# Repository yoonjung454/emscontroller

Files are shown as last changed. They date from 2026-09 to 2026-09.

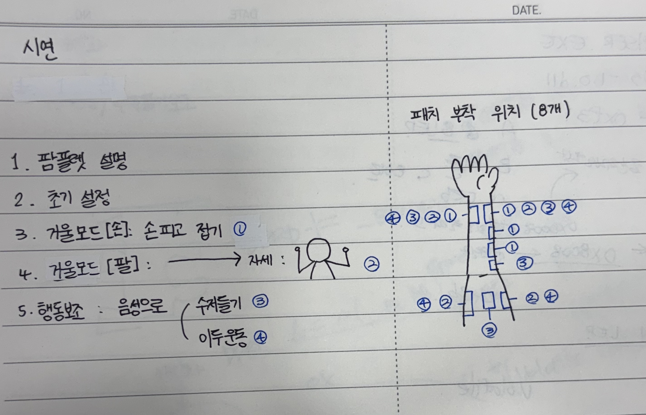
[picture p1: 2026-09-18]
docs/시연순서_패치위치선정.jpg

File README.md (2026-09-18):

# EMS Controller

EMS(전기근육자극) 기반 뇌졸중·마비 환자 재활 보조 시스템 — 한성공학경진대회 16번 팀.

카메라(MediaPipe)로 손/팔의 움직임을 실시간으로 인식해 목표 동작으로 삼고, 그 목표에
가까워지도록 EMS 자극 세기를 자동으로 조절하는 폐루프 제어 시스템입니다.

```
[카메라] --MediaPipe 인식--> [PC: 웹앱]
                                  |  목표 vs 실제 오차 계산 → 폐루프 제어값(0~100) 산출
                                  v
                       [Web Serial, 19200bps]
                                  v
                 [Arduino Nano + openEMSstim 펌웨어]
                                  v
                     [TENS 7000 저주파 자극기] → 전극 패드 → 손/팔 근육
```

## 폴더 구조

| 경로 | 내용 |
|---|---|
| `app.js`, `index.html`, `hand_camera.py`, `*.task`, `run_server.bat` | **웹앱** (실제 시연에 쓰는 최종 버전). `run_server.bat` 실행 후 Chrome/Edge로 `http://localhost:8000` 접속. 거울/팔 인식/행동 보조/테스트 4가지 모드 지원 (행동 보조 모드 안에 이두운동·수저 들기 보조와 "탱글이" 음성 비서가 포함됨). |
| `docs/` | 대회 제출용 보고서·전시 판넬·설계 정리 문서·시연 대본과 Q&A·시연 시 패치 위치 사진·개발 커밋 히스토리 원문·팀 대화 기반 프로젝트 진행 타임라인. |
| `hardware/case/` | 보드 케이스 3D 프린팅 설계(STL)와 조립 영상. |
| `python-ems_closed_loop/` | 웹앱 이전에 먼저 만들어진 **파이썬(Tkinter) 프로토타입**. 같은 폐루프 제어 로직을 파이썬으로 구현한 버전 (참고/백업용, 시연에는 웹앱을 사용). |
| `firmware/openemsstim_serial_controller/` | **현재 실제 보드에 올라가 있는 최신 Arduino 펌웨어** (openEMSstim 기반, PING/ARM/SET/STOP 시리얼 프로토콜). |
| `firmware/channel_alternate_test/` | 채널1/채널2가 실제로 어느 핀에서 나오는지 확인할 때 쓴 진단용 스케치. |
| `archive/early_prototypes/` | 현재 구조로 정착하기 전, 초기에 시도했던 별도의 하드웨어 프로토타입(피드백 장갑, 주먹 인식 버튼 테스트) 스케치 — 개발 히스토리 보존용, 실제 시연과는 무관. |

> 예전에는 2026-08-23 시점 구버전 스냅샷(`mediapipehand/` 폴더)과 그걸 파일
> 하나로 번들링한 `ems_demo_standalone.html`도 참고용으로 같이 두었으나,
> 이 저장소의 목적이 "최종 기록/포트폴리오"로 정리되면서 혼동을 줄이기 위해
> 삭제했습니다. 필요하면 git 히스토리에서 언제든 복원할 수 있습니다.

이 저장소에는 없지만 함께 촬영해둔 시연/조립 영상(수백 MB~1GB대 mp4)은 GitHub
용량 제한(파일당 100MB) 때문에 git에는 올리지 않았습니다 — 원본은 팀 공유
드라이브에 그대로 보관되어 있으니, 포트폴리오에 영상이 필요하면 YouTube나
Drive 링크로 별도 공유하세요.

## 안전 관련 필수 사항

- `app.js`의 `config.safety.maxIntensity`(안전 최대 제어값)는 기본값 0으로, 사람이 화면에서
  직접 값을 입력하기 전까지 실제 EMS 출력이 나가지 않습니다.
- 연속 자극 시간 제한(기본 60초)과 비상정지(스페이스바/ESC/화면 버튼)가 구현되어
  있습니다. (전체 실험 제한시간은 실사용 편의를 위해 제거했고, 경과 시간은 화면에
  참고용으로만 표시됩니다.)
- 실제 사람 몸에 전기자극을 가하는 시스템이므로, 안전 상한값은 반드시 전문가 감독 하에
  결정해야 합니다.

## 실행 방법

1. `run_server.bat` 더블클릭 (Python 필요)
2. Chrome 또는 Edge로 `http://localhost:8000` 접속
3. 모드 선택 → 카메라 실행 → 초기값(캘리브레이션) 측정 → Arduino 연결 → 안전값 설정 → 제어 시작

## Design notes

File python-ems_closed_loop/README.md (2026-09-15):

# AI 비전 피드백 기반 폐루프 EMS 손동작 제어 시스템

카메라(MediaPipe)로 손가락 굽힘 정도를 실시간으로 측정하고, 자연어 명령에서 뽑아낸 목표
굽힘값과 비교해 OpenEMSstim(Arduino Nano)에 보내는 EMS 제어값(0~100, **mA 아님**)을
자동으로 올리고 내리는 폐루프 제어 프로토타입입니다.

> ⚠️ **먼저 읽어주세요**: 이 프로그램은 사람 몸에 전기 자극을 가하는 하드웨어를 다룹니다.
> 기본 실행 모드는 항상 **시뮬레이션**이고, 실제 EMS 출력은 `--live-serial`(또는 `--live`)
> 플래그 + `config.json`의 `safety.safety_max_intensity`를 담당자가 직접 0보다 크게 설정해야만
> 나갑니다. 이 값을 임의로 정해주지 않습니다 — 아래 "안전 경고" 섹션을 반드시 읽으세요.

---

## 1. 전체 시스템 구조 요약

```
[노트북]
  자연어 명령 입력 (GUI)
        │
        ▼
  command_interpreter.py  ── 규칙 기반으로 "목표 굽힘 %" 추출 (LLM 없이 동작, 나중에 교체 가능)
        │
        ▼
  adaptive_model.py       ── 과거 세션 데이터로 "이 사람은 이 정도 자극값이면 대략 이만큼 구부러짐"을 추정
        │ (초기 자극값 제안, 항상 safety로 재검증됨)
        ▼
  controller.py            ── target% vs current% 오차 기반 폐루프 제어 (P 또는 PID, 단계 제한)
        │                          ▲
        │ EMS 제어값(0~100)         │ current% (필터링된 굽힘값)
        ▼                          │
  safety_manager.py  ◄─────────────┤   (모든 실제 출력은 여기를 반드시 통과)
        │                          │
        ▼                          │
  serial_link.py  ──USB(19200bps)──▶  Arduino Nano (openemsstim_serial_controller.ino)
        │                                   │
        │                                   ▼
        │                          EMSChannel.setIntensity() → AD5252 디지털 가변저항
        │                                   │
        │                                   ▼
        │                     외부 EMS 기기 → 패드 → 손가락 굽힘근 자극
        │
        ▼
  vision_tracker.py  ◄── OpenCV 카메라 + MediaPipe Hand Landmarker (21개 랜드마크)
        │  (검지/중지/약지/새끼 4개 손가락의 MCP/PIP/DIP 각도 → 0~100% 굽힘값)
        ▼
  data_logger.py  ── 매 tick을 CSV로 기록 (adaptive_model 학습 데이터 겸 실험 로그)
        │
        ▼
  gui.py  ── 카메라 영상, 관절, 명령창, 그래프, 비상정지 버튼 등 표시 (Tkinter)
```

시뮬레이션 모드(`simulator.py`)는 위 그림에서 `vision_tracker.py`와 `serial_link.py`를 각각
`HandDynamicsSimulator`, `SimulatedArduino`로 바꿔 끼우는 것뿐입니다. `controller.py`,
`command_interpreter.py`, `safety_manager.py`, `data_logger.py`, `gui.py`는 실제/시뮬레이션
어느 쪽이든 완전히 동일한 코드로 동작합니다.

---

## 2. 핵심 가정과 실제 장치에서 확인해야 하는 항목

이 코드는 아래 항목을 **실제로 확인**했거나, 확인이 필요하다고 명시합니다 (임의로 지어낸
핀 번호/클래스는 없습니다):

| 항목 | 상태 | 확인한 방법 / 확인해야 할 것 |
|---|---|---|
| `EMSChannel::setIntensity(int)`가 0~100을 받는다 | ✅ 확인함 | 공식 `EMSChannel.cpp` 원문 확인 (`arduino-openEMSstim.ino`도 동일) |
| 채널1 핀 = `(5, 4, A2, wiperIndex=1)`, 채널2 핀 = `(6, 7, A3, wiperIndex=3)` | ✅ 공식 예제 값 확인함 | **하지만 팀 보드가 이 배선과 같은지는 당신이 직접 확인해야 합니다** — 아래 참고 |
| `AD5252 digitalPot(0)` (I2C 주소 오프셋 0) | ✅ 공식 예제 값 확인함 | 팀 보드의 실제 I2C 주소가 다르면 `openemsstim_serial_controller.ino`의 이 줄을 수정 |
| `Serial.begin(19200)` (USB 통신 속도) | ✅ 공식 펌웨어 기본값 확인함 | `config.json`의 `serial.baud_rate`와 반드시 일치시킬 것 |
| `applySignal()`/`check()`가 millis() 기반으로 자동 정지한다 | ✅ 확인함 | 그대로 재사용 (우리가 새로 만들지 않음) |
| CH340 드라이버로 Arduino Nano 호환보드가 보인다 | ⚠️ 확인 필요 | 처음 연결 시 Windows 장치 관리자에서 "USB-SERIAL CH340" 포트가 보이는지 확인 |
| 채널 1만 정상 작동, 채널 2는 하드웨어 고장 | ✅ 팀이 알려준 정보를 그대로 반영 | `arduino/hardware_config.h`의 `CHANNEL_2_ENABLED false` |
| 사람마다 안전한 최대 자극 세기 | ❌ **이 코드는 정하지 않음** | 전문가 감독 하에 직접 결정 후 `config.json`에 입력 |
| 웹캠이 약 30~45도 방향(손등+손가락 관절이 보이는 각도)에서 촬영된다 | 권장 사항 | 카메라를 손 위쪽 대각선에서 손등을 향하도록 배치 |

**핀 배선 재확인 방법**: `arduino/openemsstim_serial_controller.ino`를 열어
`EMSChannel emsChannel1(...)`, `EMSChannel emsChannel2(...)` 두 줄을 찾으세요. 괄호 안 숫자가
팀이 실제로 납땜/배선한 핀 번호와 일치하는지 멀티미터나 회로도로 확인한 다음 진행하세요.
다르면 숫자만 실제 배선에 맞게 고치면 됩니다 (클래스 구조는 그대로 사용).

---

## 3. 프로젝트 폴더 구조

```
ems_closed_loop/
├── main.py                                  # 진입점 (CLI 인자 처리, 전체 조립, 워커 스레드 시작)
├── gui.py                                    # Tkinter GUI
├── vision_tracker.py                         # 카메라 + MediaPipe Hand Landmarker
├── command_interpreter.py                    # 자연어 → 목표 굽힘 % (규칙 기반, LLM 교체 가능 구조)
├── controller.py                             # 폐루프 제어 (P / PID)
├── adaptive_model.py                         # 개인화 모델 (선형/2차 회귀로 초기 자극값 추정)
├── serial_link.py                            # PC ↔ Arduino 시리얼 통신
├── safety_manager.py                         # 모든 안전 규칙의 단일 창구
├── simulator.py                              # 카메라/Arduino 없이 테스트하는 시뮬레이션
├── data_logger.py                            # CSV 로깅 + 과거 세션 불러오기
├── config.py                                 # 설정 데이터클래스 + config.json 로드/저장
├── config.json                               # (최초 실행 시 자동 생성됨. 안전 상한값은 0으로 시작)
├── requirements.txt
├── README.md                                 # 이 파일
├── hand_landmarker.task                      # MediaPipe 모델 파일
├── arduino/
│   ├── openemsstim_serial_controller.ino     # 공식 펌웨어 + 시리얼 명령 패치
│   └── hardware_config.h                     # 채널 활성화/BLE/타임아웃 등 우리 쪽 설정
├── tests/
│   ├── test_command_interpreter.py
│   ├── test_controller.py
│   ├── test_safety_manager.py
│   ├── test_adaptive_model.py
│   └── test_config.py
├── logs/                                      # 세션별 CSV (실행 시 자동 생성)
└── models/
    └── adaptive_model.json                    # 학습된 개인화 모델 (있으면 자동 로드)
```

각 파일은 이미 이 폴더에 전체 코드로 작성되어 있고, `python -m unittest discover -s tests`로
38개 단위 테스트가 모두 통과하는 상태입니다. (아래 "9. 시뮬레이션 실행 방법"에서 직접 확인할 수
있습니다.) 이 문서에서는 코드를 다시 옮겨 적지 않고, 무엇이 어디 있는지와 어떻게 실행하는지에
집중합니다.

---

## 4. 각 파일의 역할 (요약)

- **main.py** — CLI 플래그(`--live`, `--live-camera`, `--live-serial`)를 해석해 실제/시뮬레이션
  구성요소를 선택하고, `ControlLoopWorker`를 백그라운드 스레드로 돌리며 GUI를 메인 스레드에서 띄웁니다.
- **gui.py** — 카메라 영상, 관절, 명령 입력창, 30/60/90% 버튼, 캘리브레이션 버튼, 포트 선택,
  실시간 수치, 그래프, CSV 상태, 큰 빨간 비상정지 버튼을 그립니다. 워커의 `Snapshot`을
  주기적으로 읽어와 화면만 갱신합니다 (직접 하드웨어를 만지지 않음).
- **vision_tracker.py** — OpenCV로 프레임을 읽고 MediaPipe Hand Landmarker로 21개 랜드마크를
  뽑은 뒤, 검지/중지/약지/새끼 4개 손가락의 MCP-PIP-DIP 각도를 3D 월드 좌표로 계산해 평균 굽힘값을
  만들고, 캘리브레이션(펴짐/구부림) 기준으로 0~100%로 정규화합니다. 중앙값 필터 + EMA로 흔들림을
  줄이고, 연속 미검출 프레임 수로 "잠깐 놓침"과 "완전히 놓침"을 구분합니다.
- **command_interpreter.py** — "살짝/반쯤/꽉 쥐어", "NN% 쥐어", "정지", "종료" 등을 정규식과
  키워드 매칭으로 해석합니다. `llm_backend` 콜백을 넣으면 나중에 실제 LLM으로 교체 가능합니다.
- **controller.py** — 목표-현재 오차로 P(비례) 또는 PID 제어를 계산하고, 한 번에 바꿀 수 있는
  최대 단계(`max_step_up`/`max_step_down`)와 안정화 시간(`control_period_s`)을 강제합니다.
  허용오차 안에 `success_hold_seconds` 이상 머물면 성공으로 판정하고 즉시 0으로 내립니다.
- **adaptive_model.py** — 과거 세션에서 "목표에 안정적으로 도달했던(HOLDING/SUCCESS)" 순간의
  (자극값, 실제 굽힘값) 쌍만 골라 1차/2차 회귀를 적합시키고, 다음 실행의 시작 자극값을 추정합니다.
  데이터가 부족하면 항상 안전한 낮은 기본값을 돌려줍니다.
- **serial_link.py** — 포트 자동/수동 탐색, PING/PONG 핸드셰이크, ARM/SET/STOP/STOP_ALL/STATUS
  전송과 응답 대기, 하트비트 송신, 연결 끊김 감지를 담당합니다.
- **safety_manager.py** — `safety_max_intensity`(기본 0) 게이트, 캘리브레이션/손 인식/연결 여부
  전제조건 검사, 연속 자극 시간·전체 실험 시간·쿨다운 타이머, 비상정지 콜백을 관리하는 **유일한**
  안전 판단 창구입니다.
- **simulator.py** — 카메라 없이 자극값→굽힘값 반응(1차 지연 + 비선형 포화 + 노이즈)을 흉내내는
  `HandDynamicsSimulator`와, Arduino 없이 같은 프로토콜에 응답하는 `SimulatedArduino`.
- **data_logger.py** — 세션별 CSV 기록과, `adaptive_model.py`가 학습에 쓸 과거 세션 전체 로드.
- **config.py** — 모든 튜닝 값(제어 게인, 안전 상한, 시리얼 설정, 프리셋 %, ...)의 단일 출처.

---

## 5. Windows 설치 방법 / 6. Python 권장 버전

- **Python 3.10 또는 3.11 (64비트)** 을 권장합니다. (mediapipe/opencv의 Windows용 사전빌드
  wheel이 이 버전대에서 가장 안정적으로 제공됩니다. 이 리포지토리 자체는 3.13에서도 단위
  테스트가 통과했지만, 실제 대회 환경에서는 3.10/3.11처럼 더 널리 검증된 버전을 권장합니다.)
- [python.org](https://www.python.org/downloads/) 에서 설치할 때 **"Add python.exe to PATH"**
  체크박스를 반드시 켜세요.
- Arduino Nano(호환보드, CH340) USB 드라이버가 필요합니다. 대부분 Windows 10/11은 자동으로
  잡지만, 장치관리자에 포트가 안 보이면 "CH340 driver windows"로 검색해 제조사 드라이버를 설치하세요.

## 7. 가상환경 생성과 라이브러리 설치 명령

PowerShell 기준:

```powershell
cd ems_closed_loop
py -3.11 -m venv .venv
.\.venv\Scripts\Activate.ps1
python -m pip install --upgrade pip
pip install -r requirements.txt
```

설치 확인:

```powershell
python -m unittest discover -s tests -v
```

`OK`가 뜨고 실패한 테스트가 없으면 준비된 것입니다 (카메라/Arduino 없이도 전부 통과합니다).

---

## 8. Arduino IDE 설정 및 업로드 방법

1. Arduino IDE 설치, 보드 매니저에서 **Arduino AVR Boards** 설치.
2. 툴 > 보드 > **Arduino Nano** 선택, 프로세서는 보드에 맞게 (대부분 ATmega328P, 구형 부트로더면
   "ATmega328P (Old Bootloader)") 선택.
3. `arduino/` 폴더에 아래 라이브러리 파일들이 **이미 들어있습니다** (팀이 실제로 쓰던
   letyourbodymove/openEMSstim 원본에서 그대로 복사해둔 것 -- 수정하지 않았습니다):
   - `AD5252.cpp/.h`, `EMSChannel.cpp/.h`, `EMSSystem.cpp/.h`, `Debug.cpp/.h`
   - `AltSoftSerial.cpp/.h`, `AltSoftSerial_Boards.h`, `AltSoftSerial_Timers.h`,
     `Rn4020BTLe.cpp/.h`, `known_boards.h`, `known_timers.h` (BLE용 -- 기본 설정에서는
     `hardware_config.h`의 `ENABLE_BLUETOOTH_MODULE 0`이라 실제로는 안 쓰이지만, 다른 .cpp가
     참조하지 않으므로 폴더에 있어도 무방합니다)

   ⚠️ 팀의 실제 보드가 이 파일들과 다른 버전(예: `Serial.begin(115200)`을 쓰는 원본 등)으로
   이미 세팅되어 있었다면, 이 프로젝트의 `openemsstim_serial_controller.ino`를 업로드하는 순간
   `hardware_config.h`의 `SERIAL_BAUD_RATE`(19200)로 통일되니 신경 쓰지 않아도 됩니다.
4. 이 프로젝트가 이미 제공하는 `openemsstim_serial_controller.ino` + `hardware_config.h`는
   그대로 두세요 (핀 번호를 새로 지어내지 않고 공식 예제 값을 그대로 재사용합니다 — 2번 섹션 참고).
5. Arduino IDE에서 `arduino/openemsstim_serial_controller.ino`를 엽니다 (같은 폴더의 .h/.cpp가
   자동으로 함께 컴파일됩니다).
6. 보드가 실제로 이 핀 배선과 같은지 다시 한번 확인한 뒤 (2번 섹션), **업로드**.

   ※ 코드 업로드는 항상 USB로만 가능합니다. 블루투스(RN4020)는 프로그램이 이미 올라간 뒤
   명령을 주고받는 용도일 뿐, 코드 자체를 무선으로 넣는 기능은 이 보드에 없습니다.
7. 시리얼 모니터를 19200bps로 열면 부팅 시 다음과 같은 로그가 보여야 합니다:
   ```
   SETUP:
       BT: DISABLED (ENABLE_BLUETOOTH_MODULE=0 in hardware_config.h)
       EMS: INITIALIZING CHANNELS
       EMS: INITIALIZED
       EMS: STARTED
   SETUP DONE (LED 13 WILL BE ON)
       SIMPLE PROTOCOL READY (PING/ARM/SET/STOP/STOP_ALL/STATUS)
   ```
   시리얼 모니터에 `PING`을 입력해 보내면 `PONG`이 와야 합니다 — 이게 되면 통신 준비 완료입니다.

---

## 9. 시뮬레이션 실행 방법

**항상 이 순서로 시작하세요.** 카메라/Arduino가 전혀 없어도 전체 프로그램이 돌아갑니다.

```powershell
python main.py
```

- GUI가 뜨고, 왼쪽 상단 "모드 / 연결"에 `카메라: 시뮬레이션 / Arduino: 시뮬레이션`이 보입니다.
- 자연어 명령창에 `손을 반쯤 쥐어`를 입력하고 **실행**을 누르거나, 60% 빠른 버튼을 누르세요.
- "현재 굽힘값"이 서서히 60%로 올라가고, "EMS 제어값"도 함께 올라가다가 목표 근처에서 멈추고,
  "판단 상태"가 `목표 유지 중` → `성공`으로 바뀌는 걸 그래프로 확인할 수 있습니다.
- 30%, 60%, 90% 각각 시험해서 매번 잘 수렴하는지 확인하세요. 이게 **"이 모드로 30/60/90% 목표
  추종을 검증"** 요구사항입니다.
- `정지`/`종료` 명령, 비상정지 버튼(스페이스/ESC/화면의 빨간 버튼)을 눌러 즉시 0으로 떨어지는지도
  확인하세요.

제어기만 따로, GUI 없이 빠르게 확인하려면:

```powershell
python -m unittest discover -s tests -v
```

---

## 10. LED 또는 측정 장비를 이용한 비인체 테스트 방법

사람 몸에 붙이기 전에 반드시 이 단계를 거치세요.

1. **Arduino 단독 통신 검증** (카메라 불필요):
   ```powershell
   python main.py --live-serial
   ```
   GUI에서 포트를 선택해 연결하고, 명령창에 `손을 살짝 쥐어`를 입력해보세요. 이때 현재 굽힘값은
   시뮬레이션(HandDynamicsSimulator)이 만들어내지만, `EMS 제어값`은 **진짜로 Arduino에 SET
   명령을 보내고 있습니다**. 시리얼 모니터(또는 별도 터미널)로 Arduino가 `OK,1`을 응답하는지
   확인하세요.
2. **LED/측정 장비로 채널 1 출력 확인**: EMS 패드 대신 채널 1의 출력단에 (a) 직렬로 저항을 낀
   LED, 또는 (b) 멀티미터/오실로스코프를 연결해, `EMS 제어값`이 올라갈 때 실제로 출력(LED
   밝기, 전압/저항값)이 따라 올라가는지 확인하세요. `channel1.getIntensity()`는 STATUS 명령으로
   조회할 수 있습니다.
3. 이 단계에서 이상하면 (LED가 안 켜짐, 밝기가 이상함) — 아직 사람에게 연결하지 마세요. 배선,
   AD5252 I2C 주소, 채널 핀 번호(2번 섹션)를 다시 확인하세요.

---

## 11. 실제 장치 연결 전 체크리스트

- [ ] 위 9, 10번 단계를 모두 통과했다.
- [ ] `config.json`의 `safety.safety_max_intensity`를 **전문가 감독 하에** 사람에게 안전한
      값으로 직접 설정했다 (이 리포지토리는 절대 이 숫자를 대신 정해주지 않습니다).
- [ ] `safety.safety_min_intensity` ≤ `safety.safety_max_intensity` 인지 확인했다.
- [ ] 채널 1 전용 패드가 손가락 굽힘근(전완 굴근) 위치에 올바르게 부착되어 있다.
- [ ] 채널 2는 하드웨어 고장 상태이므로 사용하지 않는다 (코드도 이를 거부합니다).
- [ ] **하드웨어 비상정지(E-stop)가 소프트웨어와 별개로 준비되어 있다** — 이 프로그램의 비상정지
      버튼/스페이스바/ESC는 소프트웨어 레벨입니다. USB 케이블을 뽑거나 EMS 기기 자체의 전원
      스위치처럼 프로그램과 무관하게 즉시 자극을 끌 수 있는 물리적 수단을 반드시 별도로 준비하세요.
- [ ] 참가자에게 안전 주의사항을 안내했다 (아래 "안전 경고" 참고).
- [ ] 카메라가 손등/손가락 관절이 보이는 30~45도 대각선 각도로 고정되어 있다.

---

## 12. 실제 실행 방법

체크리스트를 모두 통과했다면:

```powershell
python main.py --live
```

1. GUI에서 포트를 선택하고 **연결**을 누릅니다 (PONG 응답까지 확인됩니다).
2. **① 펴짐 캘리브레이션**을 누르고 손을 쫙 편 상태를 2~3초 유지합니다.
3. **② 구부림 캘리브레이션**을 누르고 주먹을 최대한 쥔 상태를 2~3초 유지합니다.
4. 캘리브레이션 상태가 "완료"로 바뀌면 명령을 입력합니다 (예: `손을 반쯤 쥐어`).
5. 오직 이 시점부터 `safety_manager.can_arm_live()`의 모든 조건(연결/핸드셰이크/캘리브레이션/
   손 인식/시간 제한)이 통과해야 실제 ARM/SET이 나갑니다. 하나라도 실패하면 명령은 그냥
   실행되지 않고, GUI에 그 이유가 표시됩니다.

`--live-camera`만 쓰면 카메라는 실제인데 Arduino는 시뮬레이션이라 EMS 제어값 튜닝을 사람 없이도
카메라 노이즈/조명까지 반영해서 확인할 수 있습니다.

---

## 13. 자연어 명령 사용 예시

| 입력 | 결과 |
|---|---|
| `손을 살짝 쥐어` / `조금만 쥐어` | 목표 30% (설정 파일에서 조정 가능) |
| `손을 반쯤 쥐어` / `반쯤 구부려` | 목표 60% |
| `손을 꽉 쥐어` / `최대한 쥐어` | 목표 90% |
| `40% 쥐어` / `손가락을 75퍼센트 구부려` | 목표 40% / 75% (0~100 어떤 값도 가능) |
| `120% 쥐어` | 오류: "목표 굽힘 값은 0~100% 사이여야 합니다" |
| `정지` / `멈춰` / `손 펴` | 즉시 자극 정지 |
| `종료` | 프로그램 종료 (정지 명령까지 포함) |
| `쥐어` (정도 없음) | 오류: 얼마나 쥘지 명확히 말해달라는 안내 |

30/60/90 프리셋 값은 `config.json`의 `presets.light_percent` / `half_percent` / `strong_percent`
에서 바꿀 수 있습니다.

---

## 14. 예상되는 문제와 해결 방법

| 문제 | 원인/해결 |
|---|---|
| `카메라(index=0)를 열 수 없습니다` | 다른 프로그램(Zoom, 다른 파이썬 창)이 카메라를 쓰고 있는지 확인. `config.json`의 `camera.camera_index`를 0→1로 바꿔보기. |
| `PONG 응답이 없습니다 (핸드셰이크 실패)` | 포트/보율(19200) 확인, Arduino가 실제로 업로드된 상태인지, 다른 프로그램(시리얼 모니터)이 포트를 이미 잡고 있지 않은지 확인. |
| `SET` 이 계속 `ERROR,NOT_ARMED` | GUI에서 아직 연결/ARM 시퀀스가 안 끝난 상태. 연결 버튼을 먼저 누르고 손이 인식/캘리브레이션된 뒤에 명령을 실행하세요. |
| `ERROR,UNSUPPORTED_CHANNEL,2` | 의도된 동작입니다 — 채널 2는 하드웨어 고장으로 비활성화되어 있습니다 (15번 섹션 참고). |
| 손가락 %가 계속 흔들린다 | `config.json`의 `hand_tracking.smoothing_window`, `ema_alpha`를 조정 (창을 키우거나 alpha를 낮추면 더 부드러워지되 반응이 느려집니다). |
| 자극값이 목표를 지나쳐 계속 올라간다 | `control.max_step_up`을 줄이거나 `control.kp`를 낮추세요. PID 모드라면 `ki`를 낮추고 `integral_limit`을 줄이세요. |
| 시뮬레이션에서 자극값이 안 움직인다 | `safety.safety_max_intensity`를 실수로 0인 채로 두고 하드웨어 클램프를 시뮬레이션에도 적용하는 옛 버전이면 이 증상이 납니다 — 이 코드는 시뮬레이션 값에는 하드웨어 안전 상한을 적용하지 않도록 수정되어 있습니다 (그래도 이상하면 `controller.py`/`main.py`에서 `clamp_working_intensity` 사용 여부를 확인). |
| 캘리브레이션이 안 끝난다 | 펴짐/구부림 상태를 계속 카메라에 유지하세요 (기본 30프레임). 손이 화면 밖으로 나가면 그 프레임은 카운트되지 않습니다. |
| GUI가 멈춘 것처럼 느려진다 | 그래프/영상 갱신 주기(`gui.py`의 `POLL_MS`, `GRAPH_POLL_MS`)를 늘려보세요. |

---

## 15. 2채널 복구 후 확장 방법

1. `arduino/hardware_config.h`에서 `#define CHANNEL_2_ENABLED false` → `true`로 변경 후 재업로드.
   (핀 번호 `(6, 7, A3, wiperIndex=3)`은 이미 코드에 있으니 새로 추가할 것이 없습니다.)
2. `serial_link.py`/`simulator.py`는 이미 `channel` 매개변수를 받는 구조라 코드 변경이 필요 없고,
   `main.py`의 `_drive_hardware`/`_tick`에서 두 번째 컨트롤러 인스턴스를 만들어 채널 2에 연결하면
   됩니다 (예: `controller_ch2 = ClosedLoopController(config.control, safety)` 를 추가하고,
   손가락별로 다른 목표를 주고 싶다면 `vision_tracker.py`의 4손가락 평균 대신 손가락별 값을
   그대로 노출하도록 `FrameResult`를 확장하세요 — `_average_finger_bend`를 손가락별 딕셔너리로
   바꾸는 정도의 작은 수정입니다).
3. `command_interpreter.py`에 "검지만 굽혀"처럼 손가락별 명령을 추가하려면 `_PRESET_PHRASES`
   옆에 손가락 이름 키워드 테이블을 추가하고 `CommandResult`에 대상 채널/손가락 필드를 넣으세요.
4. 2채널이 되면 GUI에도 채널별 목표/현재/제어값/오차 행을 하나 더 추가하면 됩니다 (`gui.py`의
   `_build_readout_panel`이 그 패턴을 그대로 보여줍니다).

---

## 안전 경고 (반드시 읽기)

- 이 소프트웨어는 사람에게 안전한 자극 세기를 **정해주지 않습니다**. `safety_max_intensity`는
  반드시 전문가 감독 하에, 실제 참가자와 실제 장비로 별도 검증한 뒤 사람이 직접 입력해야 합니다.
- **심장박동기(페이스메이커) 등 삽입형 전자 의료기기를 사용하는 사람에게는 절대 사용하지 마세요.**
- 상처, 발진, 피부 자극이 있는 부위에는 사용하지 마세요.
- **목, 머리, 가슴을 가로지르는 위치**에는 절대 패드를 부착하지 마세요.
- **승인된(regulation-approved) 외부 EMS/TENS 기기와 그 전용 패드만** 사용하세요. OpenEMSstim은
  자체적으로 자극 신호를 만들지 않는 "진폭 조절기"일 뿐이며, 신호 자체는 외부 EMS 기기가 만듭니다.
- 이 프로그램의 비상정지(스페이스바/ESC/빨간 버튼)는 **소프트웨어 레벨**입니다. USB를 뽑거나
  EMS 기기 전원을 직접 끌 수 있는 **하드웨어 비상정지 수단을 프로그램과 무관하게 별도로** 준비하세요.
- 군사적 용도로 사용을 금지하는 openEMSstim 원 라이선스 조건이 이 프로젝트에도 그대로 적용됩니다.

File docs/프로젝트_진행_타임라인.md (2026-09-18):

# 프로젝트 진행 타임라인

한성공학경진대회 16번 팀의 팀 카카오톡 대화(단체방 + 1:1)를 바탕으로 재구성한
개발 과정 기록입니다. 정산 금액, 연락처, 개인적인 사정/감정 표현, 팀원 간
사적인 대화는 전부 제외했고, 엔지니어링 의사결정과 진행 상황만 날짜순으로
정리했습니다.

---

## 2026년 8월 18일 (화)
- PCB 기판 및 부품(6핀 커넥터 등) 배송 도착. 기판 크기와 6핀 커넥터가 정확히
  맞는 것을 확인.
- 블루투스 모듈(RN4020)은 당장 필요 없다고 판단해 우선순위에서 제외.
- 다음날 전자상가에서 팀 전체가 모여 직접 납땜하기로 결정.

## 2026년 8월 19일 (수)
- 기존 프로젝트 구조 정리: 장갑(Flex Sensor 5개 + MPU-6050 + ESP32) → BLE →
  RN4020 → Arduino Nano → Max Pfeiffer의 오픈소스 EMS 툴킷 "LetYourBodyMove"
  → 상용 EMS/TENS → 전극 패드로 이어지는 구조. (그동안 "openEMSstim"이라 부르던
  것이 실은 LetYourBodyMove 보드였음을 이 시점에 정정.)
- 전자상가에서 팀 전체가 모여 PCB 보드·배선 납땜 진행. 보드 납땜은 완료, 전선
  납땜은 업체에 추가 의뢰.
- 양쪽 글러브의 플렉서블 센서 위치를 서로 맞추는 작업 수행.
- ESP32 기반 초기 펌웨어 초안 작성: 글러브A(센서1~5=목표값)·글러브B(센서6~10=
  실제값)의 굽힘률 오차를 계산해 자극 세기를 조절하는 폐루프 제어 코드
  (EMS/FES 파형 자체는 생성하지 않고 Serial 출력까지만 구현).
- 검증 절차 수립: ①육안검사 → ②멀티미터로 쇼트 확인 → ③Nano 자체
  Blink/Serial 테스트. 9V 배터리 입력은 Nano의 5V 핀이 아니라 VIN/레귤레이터
  경로로 들어가야 한다는 점을 확인 필요 사항으로 기록.
- 2채널 중 1채널만 정상 동작, 2채널 미동작 문제 최초 발견 (모든 게이트를 열어도,
  2채널 게이트만 여는 정정 코드로도 동작 안 함 → 배선/기판 자체 문제 가능성).

## 2026년 8월 20일 (목)
- 2채널 문제 추가 진단: 1번선을 2번 구멍에 꽂으면 작동 안 하지만 2번선은 어느
  구멍에 꽂아도 작동 → 보드 2번 채널 회로(접점 불량 또는 신호 간섭) 문제로 추정.
- Nano 보드에 배터리를 꽂아야 EMS 전류가 흐르는 구조로 코드 정리, 안전상 문제
  없음을 확인.

## 2026년 8월 21일 (금)
- 선 자체는 문제없음을 확인. 기판 내부 문제 여부를 확인하려면 실제 신호를
  넣고 테스트해야 한다는 판단.
- 원인 후보 3가지로 정리: (1) 기판 소자 삽입 오류, (2) 납땜 불량, (3) 소자
  자체 불량. 예비 소자를 챙겨 수리업체에 진단 의뢰하기로 결정.

## 2026년 8월 22일 (토)
- 온라인(디스코드)으로 진행 상황 공유.

## 2026년 8월 23일 (일) — ★ 플렉스 센서 → 카메라(MediaPipe) 방식 전환 ★
- 플렉스 센서 글러브를 구부려도 값이 안 나오는 문제를 조사하던 중, 고무 커버를
  뜯어 확인해보니 납땜이 금속 접점이 아닌 플라스틱 위에 되어 있고 전선이 내부
  여러 곳에서 끊어져 있는 것을 발견 (멀티미터로 저항 측정 시 굽혀도 저항 변화
  없음 — 최소 2개 이상 센서 완전 단선).
- 예선 제출 기한 내에 플렉스 센서를 재조달/수리하는 것이 현실적으로 불가능하다는
  결론에 도달.
- 한 팀원이 "지금 컴퓨터로 해보는 방법"이라며 카메라 기반 손 인식 방식을
  팀에 제안 (오후 2:25경). 스스로 "임시방편"이라 표현하며 다른 대안이 있으면
  계속 제시해달라고 요청.
- 같은 날 저녁, 카메라 기반 버전이 이미 상당 부분 동작함을 확인 ("일단 카메라로
  얼추 완성함, 2채널만 되면 이대로 가도 될듯").
- 밤 11시경, 그 팀원이 새 아키텍처를 정리해 공유: "AI 비전 피드백 기반 폐루프
  EMS 손동작 제어" — MediaPipe로 왼손 목표 동작을 측정하고 오른손 EMS로 실제
  자극을 주어 오차 기반 자동 보정하는 폐루프 구조. 이 시점까지 이미 완료된 것:
  양손 인식·굽힘% 계산, 캘리브레이션, 자연어 명령 처리(규칙 기반 + Gemini API),
  Arduino(OpenEMSstim 패치) ↔ PC 시리얼 프로토콜, 실제 팔 자극 테스트, 비례
  폐루프 제어(±5% 도달 시 자극 차단), 각종 안전장치, 개인화 캘리브레이션(자극값
  20/40/60/80 순차 테스트로 개인별 반응곡선 생성 — 지도교수 제안 반영).
- 참고: 하드웨어(EMS 자극, Arduino/OpenEMSstim, PCB)는 그대로 유지되고, 바뀐
  것은 "목표 동작을 측정하는 방식"이었다 (플렉스 센서 글러브 → 카메라 기반
  손 관절 인식).
- 같은 날, 지도교수 피드백을 통해 여러 후보 주제 중 "개인별 근육 반응 학습
  기반 EMS 개인화" 방향이 학부 프로젝트 범위로 적합하다는 의견을 받아, 이후
  주제를 구체화하는 근거가 됨.

## 2026년 8월 24일 (월)
- PCB 2채널 문제를 배선 문제로 최종 확인하고 해결 (배선을 다시 꽂아 해결).
  이후 2채널 모두 정상 동작.
- 웹앱 최종 파일(mediapipehand, openemsstim_serial_controller) 공유.
- 자연어 명령 해석에 Gemini API를 사용하기로 확인.
- 버그 발견: 목표에 덜 도달했을 때 자극 세기가 너무 천천히 올라가 충분한
  전류가 전달되지 않는 문제 확인 — 이후 세션들에서 반복적으로 다뤄지는 "속도
  튜닝" 이슈의 시작점.
- 채널1/2를 3초씩 번갈아 구동하는 테스트용 Arduino 펌웨어 공유.
- 손동작 시연을 위한 참고 영상(주먹 쥐기, 엄지 펼치기 등) 수집.
- 1차 예비 심사 보고서 초안 작업 시작.

## 2026년 8월 25일 (화)
- AI로 전체 펌웨어(5000줄 이상, 상호 의존적 구조)를 통째로 재작성하는 방식은
  시간상 불가능하다고 판단, 차선책으로만 남기기로 함.
- 남은 작업 목록 정리: 손가락별 굽힘값 출력, 채널별 독립 전류 제어, 개인화
  (회원 등록) 기능, 버튼 기반 동작 추가.
- EMS/FES 활용 분야·안전 수칙 리서치를 바탕으로 "카메라 기반 필요시 보조
  (assist-as-needed) 폐루프 재활"이 프로젝트에 가장 적합한 방향으로 제안됨.
- 음성/자연어 명령으로 특정 동작을 실행하는 기능 아이디어 논의 시작.

## 2026년 8월 26일 (수)
- 전극 부착 위치 탐색 및 코딩 작업 일정 조율.

## 2026년 8월 27일 (목)
- 실제 자극 테스트로 확인된 동작: 쥐는 힘(중지·약지 강함, 새끼 약함), 이두근
  굽힘/이완, 팔꿈치 안쪽 굽힘 등 — 이를 일상생활 동작과 연결하는 논의.
- 뇌졸중·편마비 재활 관점의 설명 문구/발표 대본 초안 작성 (정상 손 동작을
  기준으로 마비된 손에 EMS 자극을 주어 동일 동작을 재현 → 감각 피드백을 통한
  신경가소성 촉진이라는 컨셉 확정).
- 시연 시나리오 작성: 거울 모드 실행 → 캘리브레이션 → 안전값 설정(최대 제어값
  90, 최대 자극시간 55초) → 아두이노 연결 → 왼손 동작을 오른손 EMS로 실시간
  재현 → 오차 ±5% 이내 도달 시 완료 → 비상정지 버튼 동작 확인.
- 개인화 기능(회원별 최적 자극값 저장/불러오기) 및 음성 인식 기능("수저 들기
  보조 실행", "이두운동 실행") 구상 — 뇌졸중/마비 환자가 직접 세팅하기 어려운
  점을 고려.
- 채널1/2를 키보드 입력으로 직접 켜고 끄는 테스트용 펌웨어 공유.
- 1차 예비 심사 보고서 초안, 시연영상 기획안 작성/공유.

## 2026년 8월 28일 (금) — 예선 제출
- 개발 세션 전체를 시간순으로 정리한 개발기록 보고서 작성. 이 시점까지의
  핵심 아키텍처: 카메라 한 대로 왼손(목표, SOURCE)·오른손(측정, ACTUAL)을
  동시에 MediaPipe HandLandmarker(21랜드마크, 2손 추적)로 인식 → 목표-실제
  오차를 비례(P) 제어기에 넣어 채널1(구부림)/채널2(폄) 세기 산출 → Web Serial
  API로 아두이노 전송 → AD5252 디지털 포텐셔미터로 세기 조절 → 외부 EMS/TENS가
  실제 자극 발생.
- 이 시점까지 발견·수정된 대표 버그: 채널1/채널2 핀 배선이 실제와 반대로 되어
  있던 버그, `EMSChannel::deactivate()` 이후 `check()`가 호출되지 않아 릴레이가
  완전히 꺼지지 않던 버그, 실시간 왼손 연동 값이 UI 정리 과정에서 계산 로직까지
  삭제되어 미갱신되던 버그, 음성인식 변수 선언 순서 문제(TDZ) 사전 발견.
- 제어 방식을 "오차 시 전류 차단 후 자연 이완 대기"에서 "채널1(구부림)/채널2
  (폄)이 오차 방향에 따라 자동 라우팅"되는 폐루프 방식으로 재설계.
- "행동 보조 모드"(사전 정의된 동작 버튼 + 실시간 왼손 연동) 신설. 목표 도달
  판정을 펄스형 → 연속 출력형으로 바꿔 반응속도 약 2.5배 개선.
- 거울/행동보조/개인화(수동 램프업) 3모드 체제 확립. "켜자마자 꺼짐" 버그의
  원인 3가지(전체 실험 타이머 초과, 연속 자극시간 제한 초과, 화면에 안 보이던
  안전정지 상태)를 순서대로 발견해 모두 해결.
- 행동 시나리오 구체화: "수저 들기 보조"(채널1 유지 → 채널2 순차 램프업),
  "이두운동"(채널2가 상승-유지-하강-휴식 반복).
- Web Speech API 기반 음성 명령("수저들기보조", "이두운동") 추가.
- 다층 안전 설계 확정: 최대 세기 기본값 0(직접 설정 필요), 연속 자극시간 제한,
  전체 실험 타이머, 두 채널 동시 활성 구조적 방지, SPACE/ESC/화면버튼/탭
  백그라운드 전환 시 비상정지.
- 밤샘 작업으로 발표 음성 녹음, 시연 영상 편집, 발표 대본·결과보고서(hwp)
  최종 검토. 보고서 표현을 일반 독자가 이해하기 쉽게 다듬음("MediaPipe" 풀어
  쓰기, "굴곡"→"굽힘"). 제출 명의상 팀장을 정함.
- 예선 마감 전 최종 보고서와 시연 영상을 이메일로 제출 완료.

## 2026년 9월 8일 (월)
- 예선 통과 확인, 본선(9월 17일) 진출 확정.
- 경쟁작 중 카메라(MediaPipe) 기반 로봇손 제어 프로젝트가 있음을 확인, EMS
  폐루프 재활이라는 방향성이 차별점이 있다고 판단.

## 2026년 9월 9일 (화)
- 본선 진출자 명단에 팀이 정상적으로 포함되어 있음을 재확인.

## 2026년 9월 10일 (수)
- 본선용 온라인 팜플렛 제출 규정 확인(작품 개요 500자 이내, 주요 적용 기술,
  참여 학생 이력, 지도교수 등).
- 작품 개요 초안 작성: "MediaPipe 손 관절 인식 + EMS 하드웨어 결합 AI 비전
  피드백 폐루프 제어 시스템". 주요 기술 목록화: MediaPipe Hand Landmarker(21개
  랜드마크), 3D 관절각 기반 굽힘도 계산, 중앙값+EMA 노이즈 필터링, 비례(P)
  폐루프 제어, Web Serial API 기반 Arduino 직결 통신(별도 프로그램 설치
  불필요), 안전 제어, 개인화 캘리브레이션, 자연어/AI 명령 인터페이스.

## 2026년 9월 11일 (목)
- 팜플렛 최종 문구(작품 개요, 적용 기술, 참여 학생 이력, 지도교수) 작성 및
  제출. 전시 이미지 3장 선정(시연 장면, 제작한 PCB 보드 사진, 시스템 구성도).
- **코드-보고서 불일치 발견**: 팀 공식 예비심사 보고서와 8/23 구버전 코드는
  오차 ±5% 도달 시 "즉시 차단"으로 기술되어 있었으나, 실제 최신 실행 코드는
  오차 해소 후에도 세기를 유지하다가 "LOCKED" 상태가 되어 수동 해제 버튼을
  눌러야 정지하는 방식으로 이미 바뀌어 있음을 코드 검토로 확인. 대회 전 코드를
  되돌리거나 문서 표현을 맞추는 것 중 하나를 팀이 결정해야 한다고 지적됨 →
  **"오차 ±5% 도달 시 LOCKED(자세 유지) 방식 유지"로 최종 확정**.
- 구버전 시연 파일(ems_demo_standalone.html 등)이 8/23~24 시점 것이라 음성명령·
  개인화·2채널 기능이 빠져 있음을 확인, 시연은 반드시 최신 버전(run_server.bat)
  으로 하도록 팀에 공유.
- 팀장 컴퓨터로 작업을 이관하는 "이사 패키지" 작업 진행: 웹앱, 파이썬 버전,
  아두이노 펌웨어, 시연 영상/발표자료/보고서를 모아 정리하고 구버전은 별도
  폴더로 분리, 필요한 설치 목록(Python, 브라우저, Arduino IDE, CH340 드라이버
  등) 정리.

## 2026년 9월 14일 (일)
- 이사 패키지에 추가 작업분 공유. 팀 내 Git을 이용한 공동 작업 도입 검토 시작.
- 전시판넬(A2) 초안 공유. 잔여 작업 목록 정리: 패치 구매, 케이스 제작, 판넬
  제작, 기능 추가(개인화 고도화, AI 의도파악 기반 명령 실행, 지원 동작 확대).
- PCB 보드 실측 후 3D 모델링으로 케이스와 뚜껑 제작 시작.

## 2026년 9월 15일 (월)
- 안전장치를 끄고 빠르게 하드웨어만 테스트할 수 있는 "테스트 모드" 추가
  (키보드 방향키로 채널1/2 즉시 자극 트리거).
- 케이스/뚜껑 3D 프린트 반복 제작. 전시판넬 최종본 완성 및 인쇄 발주. 배터리,
  추가 전극 패치 구매 완료.

## 2026년 9월 16일 (화)
- 음성 인식 UX를 버튼 방식에서 웨이크워드 방식("탱글아"/"탱그라" 호출)으로
  전환. "수저들기 보조", "나 밥먹고싶어" 등 다양한 자연어 표현 인식, "이두운동
  해줘" 시 반복 횟수를 되묻는 대화형 흐름 추가.
- 인쇄된 판넬 수령, 3D 프린트 케이스 마감 작업.
- 실제 팔에 전극을 부착해 근육 위치 재탐색, 확인된 동작 목록 확정: 주먹 쥐기,
  손목 굽힘, 이두근 굽힘(2가지 변형), 특정 채널 순서로만 되는 "손인사" 동작.
- 최종 기능 정리: 모드를 거울/팔 인식/행동 보조/테스트 4가지로 확정. 안전정지
  조건을 "시리얼 연결 끊김/연속자극 시간 초과"로 단순화. 팔 인식 모드는 손+
  팔꿈치 동시 폐루프 제어로 확장, 좌우 인식 반전 버그 수정, Pose 모델을
  lite→full로 교체해 정확도 개선. 행동 보조 모드는 회원번호 시스템을 삭제하고
  동작별 저장 방식으로 단순화. 음성 비서 "탱글이"에 Gemini 기반 자유발화 인식과
  마이크 자동 재시작(워치독) 추가. 전체 코드는 GitHub 저장소로 이관.

## 2026년 9월 17일 (수) — 본선 당일
- 최종 시연 대본 확정: 거울 모드(초기값 측정 → 안전 설정 → Arduino 연결 →
  왼손 연동 → 제어 시작) → 팔 인식 모드(손+팔꿈치 동시 제어) → 행동 보조
  모드(음성 명령으로 이두운동 실행, 버튼으로 수저들기 보조 시연).
- 전시 자료 준비 및 반입, 본선 발표 진행.

---

## 참고: 플렉스 센서 → MediaPipe 전환 경위 요약

초기 설계는 양손에 플렉스 센서 장갑(ESP32 기반)을 착용해 굽힘값을 직접
측정하는 방식이었습니다. 2026년 8월 23일, 장갑을 분해 점검하는 과정에서 센서
배선이 다수 단선된 것을 발견했고, 예선 제출 기한 내 수리·재조달이 불가능하다고
판단했습니다. 이때 한 팀원이 카메라(MediaPipe)로 손 모양을 인식하는 방식을
"지금 컴퓨터로 해보는 방법"이라는 임시방편으로 제안했고, 같은 날 안에 상당
부분 동작하는 프로토타입까지 만들어졌습니다. 이후 이 방식이 하드웨어 고장
위험이 없고 비용도 더 저렴하다는 장점이 확인되면서, 임시방편이 아니라 최종
아키텍처로 채택되어 지금의 웹캠 기반 시스템으로 이어졌습니다. (EMS 자극
하드웨어 자체는 그대로이고, 바뀐 것은 "목표 동작을 무엇으로 측정하는가"입니다.)

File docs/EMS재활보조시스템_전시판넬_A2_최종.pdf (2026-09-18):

### 01 개발 배경

# 재활의 핵심은 반복 움직임과 감각 피드백

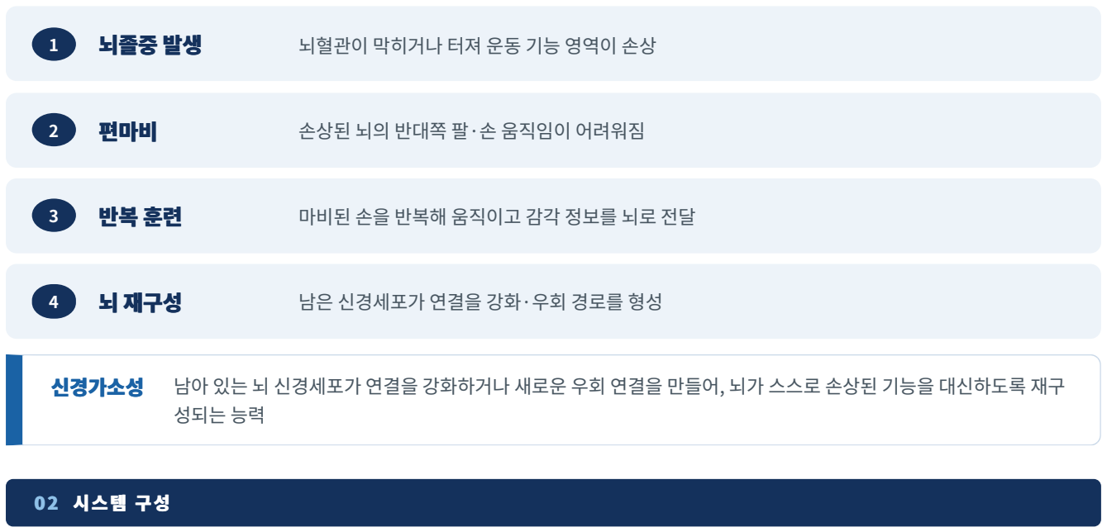
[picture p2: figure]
뇌졸중 발생; 뇌혈관이 막히거나 터져 운동 기능 영역이 손상; 편마비; 손상된 뇌의 반대쪽 팔·손 움직임이 어려워짐; 마비된 손을 반복해 움직이고 감각 정보를 뇌로 전달; 뇌 재구성; 남은 신경세포가 연결을 강화·우회 경로를 형성; 성되는 능력; 02 시스템 구성

신경가소성 남아 있는 뇌 신경세포가 연결을 강화하거나 새로운 우회 연결을 만들어, 뇌가 스스로 손상된 기능을 대신하도록 재구

# EMS와 openEMSstim — 자극 세기까지 컴퓨터가 제어

1 | 제어 PC | 동작 인식·폐루프 제어 소프트웨어
2 | openEMSstim | 직접 제작한 제어 보드 (Arduino Nano)
3 | TENS 자극 장치 | 저주파 파형 생성, 2채널 출력
4 | 전극 패치 · 근육 | 팔 근육에 부착 → 수축 → 손 동작 발생
제작한 제어 보드 Arduino Nano + 커스텀 PCB | TENS 자극 장치 전극 패치 2채널

적용 효과 기존에는 사람이 다이얼로 세기를 조절해야 했지만, 적용 후에는 시작·정지와 자극 세기까지 컴퓨터가 실시간으로 제 어한다

### 03 하드웨어 제작

# 공개 설계 파일로 기판을 제작 의뢰해 직접 실장

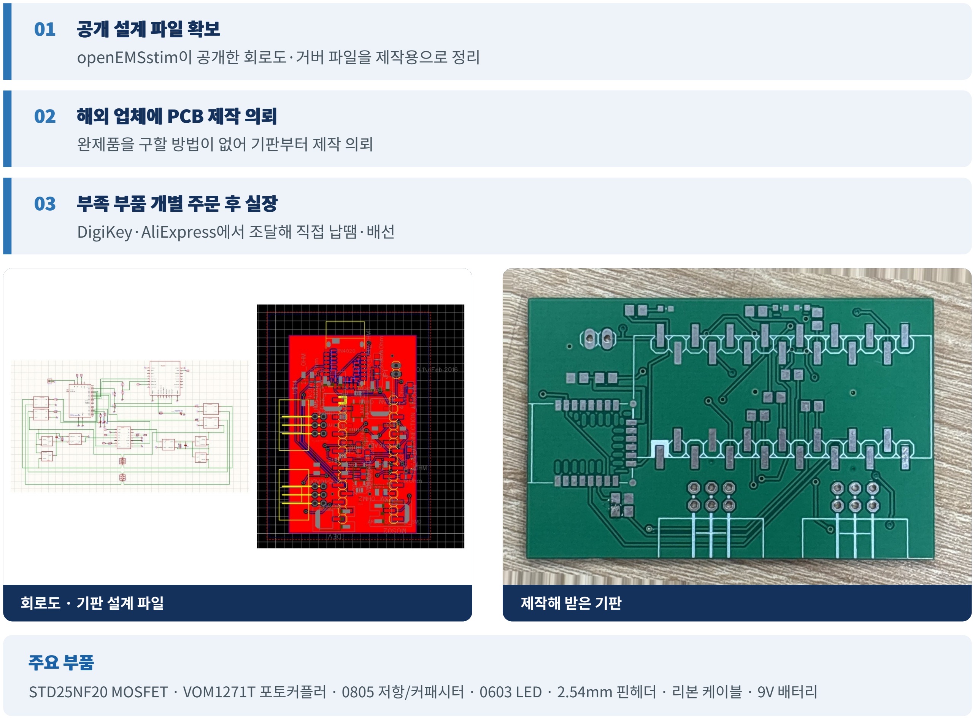
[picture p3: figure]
01 공개 설계 파일 확보 openEMSstim이 공개한 회로도·거버 파일을 제작용으로 정리; 02 해외 업체에 PCB 제작 의뢰 완제품을 구할 방법이 없어 기판부터 제작 의뢰; 03 부족 부품 개별 주문 후 실장 DigiKey·AliExpress에서 조달해 직접 납땜·배선; 회로도 · 기판 설계 파일; 제작해 받은 기판

STD25NF20 MOSFET · VOM1271T 포토커플러 · 0805 저항/커패시터 · 0603 LED · 2.54mm 핀헤더 · 리본 케이블 · 9V 배터리

### 04 핵심 기능 ①

# 비전 기반 폐루프 동작 재현

### 1 건강한 손 촬영

손가락 굽힘 정도를 측정해 목표값으로
설정

### 2 마비된 손 촬영

현재 굽힘 정도를 실시간으로 측정

실시간
폐루프 제어

### 4 EMS 자극 출력

보정된 세기로 마비된 손 근육 자극

### 3 오차 계산 및 보정

목표값과 현재값의 차이로 자극 세기 계
산

자동 보정 규칙

↑

굽힘이 부족하면
자극 세기를 높임

↓

목표값에 가까워질수록
올리는 폭을 줄임

✓

오차 ±5% 이내
목표 도달 → 자세 유지

MediaPipe 손 관절 인식으로 굽힘 각도 측정 → 비례 제어로 자극 세기 보정 → 굽히는 근육과 펴는 근육 두 채널 자동 전환

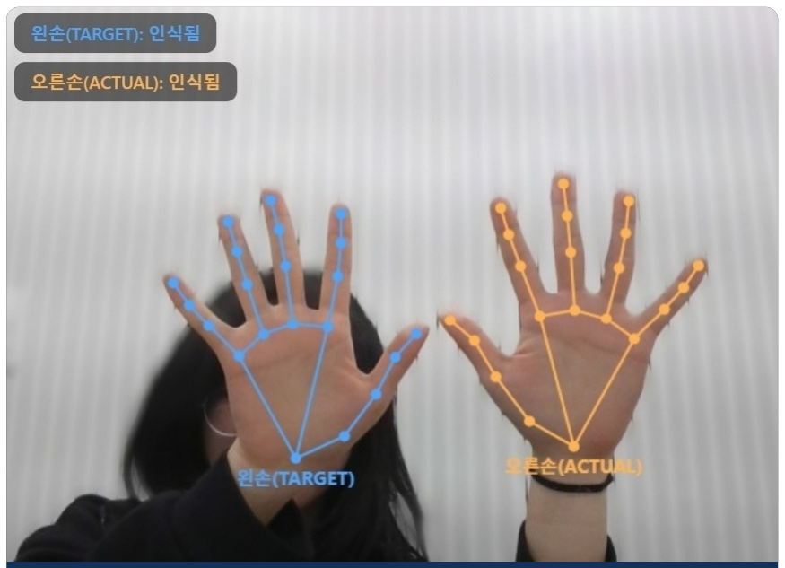
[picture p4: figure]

두 손 동시 인식 왼손 TARGET · 오른손 ACTUAL, MediaPipe 21개 관절 검출

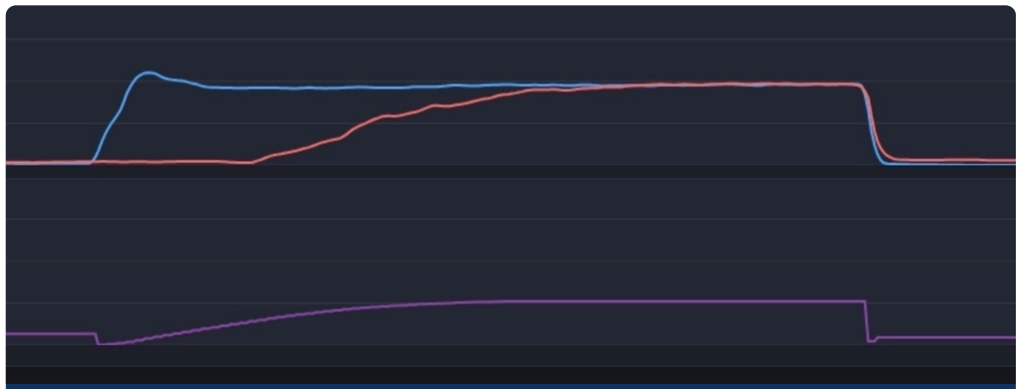
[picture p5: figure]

폐루프 수렴 기록 파랑 목표값 · 빨강 실제값 · 보라 EMS 제어값

### 05 핵심 기능 ②

# 음성 명령 기반 개인화 동작 보조

STEP 1 사전 설정
사용자마다 필요한 동작과 알맞은 자극 세기를 회원번호별로 저장
STEP 2 음성 호출
동작 이름을 말하면 저장된 설정을 불러와 즉시 실행 — 버튼 조작 불필요
저장된 동작 | 자극 패턴
수저 들기 보조 | 채널1 2초 점진적 증가 → 채널2 3초 점진적 증가
이두운동 | 채널2 상승 3초 · 유지 1초 · 하강 3초 반복

### 06 실험 결과

# 결과 : 70회 시행, 오차 ±5% 이내 수렴 확인

70회

손가락 굽힘 시행

69/70

| ±5% 이내 도달 · 98.6%

7.28초

평균 도달 시간

반복할수록 근육 피로로 도달 시간이 늘고 더 높은 자극값이 필요했으나, 폐루프 제어가 이를 자동으로 보정해 목표에 도달함

### 07 차별점 · 안전장치

# 정해진 자극의 반복이 아니라, 반응을 보고 조절

일반 저주파 자극 장치 | 본 시스템

안전장치
90

최대 제어값 상한

55초

최대 자극 시간 제한

## 즉시 차단

이상 반응 시 비상정지

현 재 성 과
2채널 그립·팔꿈치 구부림 동작 구현
폐루프 안정화 및 오차 ±5% 수렴 확인

기 대 효 과 · 향 후 계 획
AI 음성 의도 해석 · 손가락별 정밀 제어
소형화·무선화를 거쳐 실제 재활 현장 적용

기 술 스 택
MediaPipe Hand Landmarker · Web Serial API · Arduino Nano(openEMSstim) · JavaScript · Python · OpenCV

2 0 2 6 한 성 공 학 경 진 대 회 본 선

# EMS 기반 뇌졸중·마비 환자 재활 보조 시스템

### MediaPipeHand 정상 손의 움직임을 목표로, 마비된 손의 자극 세기를 스스로 조절합니다

16번 팀

팀장 홍서준 · 임승규 · 이윤정 · 이상윤
한성대학교

미리 설정된 세기를 그대로 반복
손이 실제로 얼마나 움직였는지 확인하지 않음
사용자별 반응 차이를 반영하기 어려움

정상 손의 목표값과 마비 손의 실제 반응을 함께 측정 오차에 따라 자극 세기를 스스로 조절
사용자별 움직임 범위·근육 반응을 반영

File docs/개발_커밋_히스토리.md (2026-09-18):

# 개발 커밋 히스토리 (원문)

이 프로젝트를 만들면서 쌓인 git 커밋 메시지를 시간순(오래된 것부터)으로
그대로 모아둔 기록입니다. 내용은 고치지 않고 원문 그대로 실었고,
읽기 편하게 날짜/커밋 해시로 구분만 해뒀습니다. 총 71개 커밋.

---

### 2026-09-14 18:53 — 513bf32

베이스라인: 팔꿈치(Pose) 추적 추가 전 상태

---

### 2026-09-14 19:12 — cbe1859

팔 인식 모드 추가 (Pose Landmarker 기반 팔꿈치 굽힘 폐루프 제어)

---

### 2026-09-15 13:14 — 8920336

Initial commit

---

### 2026-09-15 13:19 — 12d5090

merge: GitHub 저장소 초기 커밋과 병합

---

### 2026-09-15 14:29 — d0a39d1

파이썬 프로토타입/펌웨어 폴더 추가 + README 작성

---

### 2026-09-15 15:23 — 536ced3

테스트 모드 추가 (방향키로 채널1/2 즉시 테스트, 안전 최대값/비상정지만 유지)

---

### 2026-09-15 16:10 — 7c89271

테스트 모드: 안전 최대값 클램프·비상정지 상태 체크 제거 (전기 주기+세기 설정만 남김)

---

### 2026-09-15 16:14 — 5880d6a

개인화 모드를 행동 보조 모드 안으로 통합 (모드 4개로 축소, 상호 정지 로직 추가)

---

### 2026-09-15 16:44 — 5aaf11c

팔 인식 모드에 손 굽힘 참고 표시 추가 (팔꿈치+손 동시 측정, 페이지 정리)

---

### 2026-09-15 17:00 — 0e62780

버그 수정: 팔 TARGET/ACTUAL 역할을 매 프레임 x좌표로 재판정하던 걸 고정 판정+체크박스로 변경

---

### 2026-09-15 17:04 — 7290955

버그 수정: 테스트 모드 방향키 반복입력이 시리얼 큐에 쌓여 정지가 늦어지던 문제 (재전송 간격 제한)

---

### 2026-09-15 17:09 — 58e10a2

팔 인식 모드: 손(채널1)/팔꿈치(채널2) 동시 독립 폐루프로 확장 (부위별 채널 분리)

---

### 2026-09-15 17:13 — ae483a1

버그 수정: 팔 인식 모드 좌우 반전(손처럼 미러링 화면에서 기본적으로 뒤집혀 인식됨)

---

### 2026-09-15 17:18 — d974141

비상정지 전수 점검: safetyTripped를 트립 순간만이 아니라 매 tick 확인하도록 수정 (거울모드/팔인식모드/개인화캘리브레이션) + 팔 인식 모드 과도굽힘 시 세기 감소 기능 추가

---

### 2026-09-15 17:25 — 71f4309

속도 조정: 오르내리는 속도를 동일하게 통일하고 30%p 감속 + 팔인식모드 프레임마다 갱신되던 속도 제한 버그 수정 + localStorage에 안 쓰이는 control 값 고정되던 문제 수정

---

### 2026-09-15 17:28 — 7070ce4

속도 재조정: 원래값과 30% 감속값의 중간으로 (kpUp/Down=0.017, maxStep=0.85)

---

### 2026-09-15 17:31 — 6e1d22e

속도 3배로 상향 (kpUp/Down=0.051, maxStep=2.55)

---

### 2026-09-15 17:39 — 26131b9

행동 보조 모드를 목표 %(카메라 폐루프) 자동 세팅 방식으로 전환

- 수저 들기 보조/이두운동: 채널1/2 전류 직접입력 -> 손/팔꿈치 목표 % 입력으로 변경
- 팔 인식 모드의 stepFlexOnlyAxis/driveArmHardwareIfNeeded 폐루프 엔진 재사용
- 이두운동: 굽힘/이완 반복이 고정 시간표 대신 실제 목표 도달(LOCKED) 기준으로 자동 진행
- 시작 전 손+팔 캘리브레이션 확인, 팔 인식 모델 자동 로딩
- 회원 개인화 저장값을 채널 전류 -> 목표 %로 변경
- 행동 보조 모드에서도 필요할 때 Pose 모델 실행되도록 렌더루프 조건 확장
- (버그) 개인화 모드(수동 램프업)가 삭제된 driveActionChannels를 호출하던 걸 발견해 같이 수정

---

### 2026-09-15 17:44 — 1a9a1df

버그 수정: 팔 인식 모드 하드웨어 재전송 주기가 TTL보다 길어서 자극이 끊겼다 이어졌다 하던 문제 (600ms로 단축) + 속도 2배 상향

---

### 2026-09-15 18:06 — 98feea3

팔 인식 모드 속도/유지 버그 수정, 수저 들기 순차 진행, 전 모드 팔 인식 확대

- 세기 증가/감소가 큰 폭으로 "점프"해 보이던 문제를 고쳤다: maxStepUp/
  maxStepDown을 5.1 -> 1로 낮춰 진짜 1씩 점진적으로 오르게 하고,
  controlPeriodMs를 6000 -> 2250(실제 주기 900ms)으로 조정해 목표 도달
  시간이 대략 예전의 2배가 되도록 맞췄다.
- 목표에 도달해 LOCKED로 계속 유지하는 상태가 config.safety.
  maxContinuousStimSeconds(연속 자극 제한, 기본 10초)에 그대로 걸려 "몇 초
  뒤 혼자 꺼짐"으로 보이던 문제 수정 -- 기본값을 60초로 올리고, 이미
  localStorage에 저장된 옛 기본값(10초 이하)도 새 기본값으로 마이그레이션.
- 행동 보조 모드의 "수저 들기 보조"를 손(채널1)+팔꿈치(채널2) 동시 유지
  방식에서, 손이 먼저 목표에 도달하면 전류를 멈추고 팔꿈치(채널2)로
  진행하라고 안내하는 순차 진행 방식으로 변경 (이두운동은 손을 운동 내내
  계속 쥐고 있어야 해서 기존 동시 유지 방식 그대로 둠).
- "거울 모드 제외 모든 화면에서 팔 인식 가능하게" 요청 반영: renderLoop의
  Pose 모델 실행 조건에 테스트 모드를 추가(테스트 모드 진입 시 모델 미리
  로딩도 추가). 테스트 모드의 방향키 전류 출력 자체는 카메라와 무관하게
  그대로 동작하고, 카메라를 켜두면 손/팔 스켈레톤이 참고용으로 화면에
  같이 표시되는 것만 추가됨.
- 행동 보조 모드가 이미 폐루프(자동 세팅)로 바뀐 뒤에도 모드 설명 문구가
  옛 오픈루프(고정 전류 직접 입력) 시절 설명 그대로 남아있던 것을 수정.

Co-Authored-By: Claude Sonnet 5 <noreply@anthropic.com>

---

### 2026-09-15 18:09 — 4f5eb75

행동 보조 모드에서 팔 인식이 안 되던 문제 수정

renderLoop의 Pose 실행 조건이 행동 보조 모드에 한해서만
"runningActionKey !== null"(실행 버튼을 눌러야만) 켜지게 되어 있어서,
화면에 들어가기만 하고 아직 실행 전이면 팔 인식이 전혀 안 됐다
(테스트 모드는 appMode 조건 하나뿐이라 바로 됐음). 거울 모드를 제외한
모든 모드에서 화면 진입 즉시 Pose가 켜지도록 통일 -- 카메라 시작 시
모델을 미리 불러오는 조건, setAppMode의 사전 로딩 조건도 함께 맞춤.

Co-Authored-By: Claude Sonnet 5 <noreply@anthropic.com>

---

### 2026-09-15 18:16 — 1f39681

수저 들기 보조: 팔꿈치 목표 도달해도 전류가 안 멈추던 버그 수정

spoonLiftTick의 마지막 단계("elbow" LOCKED -> "done")에서 phase만
바꾸고 더 이상 stepFlexOnlyAxis를 호출하지 않게 해뒀는데, 그러면
actionElbowCtrl.intensity가 마지막 계산값에 "그대로 얼어붙은 채" 계속
하드웨어로 재전송됐다 -- 목표만큼 구부러졌는데도 전류가 안 멈추던
원인. 팔꿈치까지 목표에 도달(LOCKED)하면 실제로 stopActionMode()를
불러 두 채널 다 0으로 정지하고 행동을 완료 처리하도록 수정 (이두운동의
마지막 반복 완료 처리와 동일한 방식으로 통일).

Co-Authored-By: Claude Sonnet 5 <noreply@anthropic.com>

---

### 2026-09-15 21:42 — 2161cad

개인화 측정(수동 램프업)을 안전 최대값 설정 도구로 재연결

수저/이두운동이 폐루프(목표%)로 바뀐 뒤로 이 측정값이 화면에만 표시되고
어디에도 안 쓰이던 문제를 "재사용"으로 해결. A키로 멈춰서 잰 세기를
"🛡 이 값을 안전 최대값으로 설정" 버튼으로 config.safety.maxIntensity(③
카드)에 바로 채워 넣을 수 있게 함 -- 폐루프는 카메라가 목표%에 도달할
때까지 세기를 계속 올리기만 할 뿐 그 사람이 아파하는지는 모르므로, 미리
사람마다 견딜 수 있는 한계치를 재서 상한으로 걸어두는 용도.

카드 안내 문구도 옛 오픈루프 시절("채널값을 얼마로 넣어야 할지") 그대로
남아있던 걸 새 용도에 맞게 같이 수정.

Co-Authored-By: Claude Sonnet 5 <noreply@anthropic.com>

---

### 2026-09-15 22:14 — aa61147

테스트 모드: 채널1/채널2 세기를 따로 설정 가능하게 변경

기존엔 testIntensityInput 하나를 두 채널이 같이 썼는데, ←(채널1)/→(채널2)
세기를 각각 입력하는 별도 칸(testIntensityCh1Input/testIntensityCh2Input)으로
나눴다.

Co-Authored-By: Claude Sonnet 5 <noreply@anthropic.com>

---

### 2026-09-15 22:16 — 6b93846

테스트 모드: 방향키를 누르고 있는 동안 전류가 주기적으로 끊기던 버그 수정

기존엔 브라우저의 keydown "자동 반복" 이벤트가 올 때마다 재전송하는
방식이었는데, 이 반복 간격이 OS/브라우저 설정에 따라 들쭉날쭉해서 TTL
(600ms)보다 늦게 오는 경우 그 사이 잠깐씩 전류가 끊겼다. keydown은 눌린
첫 순간에만 반응하고, 그때부터 별도 setInterval(TEST_RESEND_MS=200ms)이
키를 뗄 때까지 계속 재전송하도록 바꿔서 OS/브라우저의 키 반복 타이밍과
완전히 무관하게 끊김 없이 나가도록 수정.

Co-Authored-By: Claude Sonnet 5 <noreply@anthropic.com>

---

### 2026-09-15 22:20 — ec77722

테스트 모드: 재전송이 시리얼 큐에 밀려 주기적으로 끊기던 진짜 원인 수정

키 반복 타이밍과 무관하게 만든 지난 수정 뒤에도 여전히 "왔다 안 왔다"
하던 원인을 다시 봄 -- TEST_RESEND_MS(200ms)마다 무조건 새로 SET을
보내고 있었는데, SET 하나가 실제로 응답(OK/ERROR)받기까지 그보다 오래
걸리면(직렬 통신 왕복 지연 등) WebSerialLink의 명령 큐(_chain)에 다음
SET이 계속 쌓인다. 큐가 밀리면 실제 도착 시점이 점점 늦어져서 앞서 보낸
SET의 TTL이 먼저 만료돼 채널이 꺼졌다가, 밀려있던 다음 SET이 뒤늦게
도착해 다시 켜지는 식으로 반복된 것.

이전 전송이 아직 응답을 못 받은 상태면 이번 재전송 틱은 새로 쌓지 않고
건너뛰도록(testPulseInFlight 가드) 수정 -- 큐가 절대 밀리지 않고, 실제
재전송 간격이 통신 왕복 속도에 자연스럽게 맞춰진다. TTL도 600ms ->
1000ms로 늘려 여유를 더 줌.

Co-Authored-By: Claude Sonnet 5 <noreply@anthropic.com>

---

### 2026-09-15 22:37 — 26837cc

행동 보조 모드 개인화 측정 대대적 개편: 수동 램프업 -> 목표 도달 세기 자동 탐색

회원번호 입력 섹션 밑을 다음 순서로 재구성:
  1) 🥄 수저 보조 / 💪 이두운동 선택 버튼 2개 (지금 측정 결과를 어느 행동에
     저장할지 고르는 용도)
  2) 손 목표 %, 팔꿈치 목표 % 입력칸
  3) ▶ 개인화 측정 시작 버튼

시작하면 spoonLiftTick과 같은 원리로 손 -> 팔꿈치 순서로 전류를 자동으로
올려서, 각각 목표 ±5% 안에 들어오는 순간 전류를 멈추고 그때의 세기를
기록한다(손 기록 후 이어서 팔꿈치 측정). 회원번호가 입력돼 있으면 그
회원의 해당 행동(spoonLift/bicep) 기록에 목표%와 찾은 세기를 저장한다.

기존 "🎚 개인화 측정 (수동 램프업 -- A키로 정지)" 도구는 이 새 자동
버전으로 완전히 대체(제거)했다. 거기서 나온 부산물이던 "이 값을 안전
최대값으로 설정" 기능도 함께 제거됨 -- 필요하면 별도로 다시 만들 수 있음.

실행 버튼(수저 들기 보조/이두운동 실행)은 이제 회원의 저장된 세기를
웜스타트로 사용 -- resetActionAxisCtrls() 직후 seedActionAxisCtrlsFromMember()
로 actionHandCtrl/actionElbowCtrl.intensity를 그 값으로 채워서, 매번 0부터
다시 찾지 않고 그 세기부터 시작해 더 빠르게 목표에 도달한다. 각 실행 섹션
아래 "저장된 세기" 안내 문구(spoonLiftSeedText/bicepSeedText)로 지금 어떤
세기가 적용될지 미리 보여준다.

registerMember()가 목표%만 저장하면서 이미 찾아둔 handIntensity/
elbowIntensity를 같이 날려버리던 문제도 같이 고쳐서(기존 값을 읽어와
그대로 이어감), loadMember()도 개인화 측정 선택 상태와 저장된 세기
안내문을 함께 갱신하도록 했다.

행동 보조 모드 카드 상단 소개 문구가 옛 오픈루프 시절 설명("채널1/채널2에
직접 입력한 전류값을 그대로 내보냄") 그대로 남아있던 것도 이번에 같이
수정.

편집 후 node --check, index.html 태그 짝, id 교차 참조(HTML<->JS)까지
전부 재확인.

Co-Authored-By: Claude Sonnet 5 <noreply@anthropic.com>

---

### 2026-09-15 22:52 — 48e8d88

왼팔/오른팔 구부림 % 비대칭 버그 수정 -- 양팔 각자 보정값으로 분리

같은 각도만큼 구부려도 왼팔 %가 오른팔보다 낮게 나오던 원인: 팔
초기값 측정(펴짐/구부림)이 오른팔(actual)만 재고, 그 하나의 각도
범위를 왼팔(source)에도 그대로 재사용하고 있었다(카메라 각도/팔
길이 차이 등으로 두 팔이 실제로는 다른 각도 범위를 가짐). 이 값은
단순 표시용이 아니라 팔 인식 모드에서 왼팔 %가 오른팔의 실제 목표
(TARGET)로 그대로 쓰이므로, 표시 오차가 아니라 목표 자체가 틀어지는
문제였다.

팔 초기값 측정 시 양팔을 동시에 재서 각자 보정값(calibration.*.Arm=
오른팔, calibration.*.ArmSource=왼팔 신설)을 따로 만들도록 수정.
캘리브레이션 자세(양팔 쫙 펴짐/양팔 최대 구부림)는 원래도 양팔을
대칭으로 유지하는 게 자연스러워서 버튼/절차 추가 없이 그대로 동작.

부수적으로, armSampling 상태 구조를 { sum, count }에서 역할별
{ sums, counts }로 바꾸면서 옛 구조를 참조하던 타임아웃 중단 조건
(armSampling.count)이 그대로 남아있던 것도 발견해 같이 고침 -- 안
고쳤으면 한쪽 팔만 안 보여도 측정이 영원히 안 끝나는 새 버그가 됐을 것.

Co-Authored-By: Claude Sonnet 5 <noreply@anthropic.com>

---

### 2026-09-16 18:42 — 7773ee8

테스트 모드에 남아있던 "안전 정지 상태" 표시 제거

원인: 모드를 바꿀 때마다 호출되는 forceZeroController()가 정리 목적으로
공용 상태 표시(controlState)를 항상 "SAFETY_STOP"으로 남겨두는데,
거울/팔인식/행동보조 모드는 다음 tick에서 자기 상태로 바로 덮어써서
문제가 안 됐지만, 테스트 모드는 controlState를 아예 안 건드리는 모드라
이 값이 그대로 남아 실제로는 안전장치가 없는 모드인데도 "안전 정지
상태"가 계속 표시되고 있었다.

테스트 모드로 들어갈 때 이 표시를 바로 대기중으로 되돌리고(카메라가
꺼져 있어도 즉시 반영), 안전 정지 배너(safetyTripRow)도 테스트 모드에
있는 동안은 다른 모드에서 트립된 게 남아있어도 띄우지 않도록 함 --
testModeKeyDown/sendTestPulse는 원래도 safetyTripped를 전혀 참조하지
않으므로 표시만 실제 동작과 안 맞았던 것.

Co-Authored-By: Claude Sonnet 5 <noreply@anthropic.com>

---

### 2026-09-16 19:32 — 186a3c0

발표용: 팔 인식 모드 주요 숫자(TARGET/ACTUAL/오차/EMS 제어값) 크게 표시

.compare-value 24px -> 38px, .stim-value 32px -> 48px, .compare-label
11.5px -> 14px, .state-line 13px -> 16px로 확대(공용 CSS라 팔 인식
모드 외 다른 모드에도 동일하게 적용됨). 팔 인식 모드의 손(채널1) 섹션에
따로 걸려있던 더 작은 인라인 크기(20px/22px)도 제거해서 같이 커지게
했고, 손 상태 텍스트도 20px로 키움.

곁다리로, 안내 문구에 남아있던 "연속 자극 시간 제한(기본 10초)"도
지난번에 기본값을 60초로 올린 뒤로 안 고쳐져 있던 걸 발견해 같이 수정.

Co-Authored-By: Claude Sonnet 5 <noreply@anthropic.com>

---

### 2026-09-16 19:34 — 33390d2

발표용: "손가락별 목표 vs 실제" 표 화면에서 숨김

카드 자체를 지우면 관련 JS(updateFingerTable 등)가 참조하는 DOM이
없어져 오류가 날 수 있어, 안전하게 display:none으로 화면에서만
숨김(내부 계산/저장은 그대로 계속됨 -- 필요하면 언제든 다시 보이게
되돌릴 수 있음).

Co-Authored-By: Claude Sonnet 5 <noreply@anthropic.com>

---

### 2026-09-16 19:40 — 23e8467

회원 개인화 섹션에 "저장" 버튼 추가 (불러오기/회원 등록 옆)

registerMember()가 원래도 새 회원 등록과 기존 회원 값 갱신을 둘 다
처리하는 upsert라서, 새 로직 없이 같은 함수를 호출하는 버튼만 하나
더 추가했다 -- 이름을 몰라 헷갈리지 않게 registerMember(btn)이 실제로
눌린 버튼을 받아 그 버튼에 "저장됨!" 플래시가 뜨도록 함께 수정.

Co-Authored-By: Claude Sonnet 5 <noreply@anthropic.com>

---

### 2026-09-16 19:54 — 5ca62a3

발표용: 행동 보조 모드(수저/이두운동)도 팔인식 모드처럼 큰 숫자로 표시

지금까지 수저 들기 보조/이두운동은 손·팔꿈치 상태를 "INCREASING (12)"
같은 작은 초록색 한 줄(state-line)로만 보여줘서, 손 쪽은 그나마 ⑤
카드의 큰 ACTUAL 숫자(항상 손 평균이 표시됨)로 커버됐지만 팔꿈치 쪽은
작은 글씨로만 보였다. 팔 인식 모드의 손(채널1) 섹션과 똑같은 스타일
(TARGET/ACTUAL/오차 큰 칸 + EMS 세기 칸)을 손·팔꿈치 양쪽에 다 추가.

중복 코드를 없애려고 팔 인식 모드에서 손코딩돼 있던 TARGET/ACTUAL/오차
계산을 updateCompareBoxes() 공용 함수로 뽑아내고, 수저 들기 보조/
이두운동의 손·팔꿈치 4곳에서 재사용. 이두운동은 팔꿈치 목표가
굽힘/이완 두 개라 지금 단계(curl/hold=굽힘, release=이완) 기준으로
표시.

Co-Authored-By: Claude Sonnet 5 <noreply@anthropic.com>

---

### 2026-09-16 19:59 — c808432

모드 선택에서 팔 인식 모드/행동 보조 모드 버튼 순서 교체

Co-Authored-By: Claude Sonnet 5 <noreply@anthropic.com>

---

### 2026-09-16 20:08 — 046fed2

수저 들기 보조/이두운동 실행 버튼을 나란히 배치하고, 숫자 표시를 4개->2개로 통합

두 행동이 동시에 돌 수 없는데도(runningActionKey 하나뿐) 각자 따로
손/팔꿈치 TARGET·ACTUAL·오차·세기 칸을 갖고 있어서 화면에 항상 4벌이
같이 보였다 -- 실행 안 하는 쪽은 계속 "-"만 떠 있어서 어느 게 실제
값인지 헷갈리기 쉬웠다("수치가 안 나온다"는 것도 이 혼란 때문이었을
가능성이 큼). "손" 1벌, "팔꿈치" 1벌만 공용으로 두고, 지금 실행 중인
쪽(spoonLiftTick 또는 bicepClosedLoopTick)이 그때그때 채워쓰도록
통합했다(actionHand*/actionElbow* 이름으로 정리). 두 실행 버튼도
같은 줄에 나란히 배치.

각 행동 고유의 목표 % 입력칸(spoonLift/bicep)과 "저장된 세기" 안내
문구는 행동별로 다른 값이라 그대로 각자 유지.

Co-Authored-By: Claude Sonnet 5 <noreply@anthropic.com>

---

### 2026-09-16 20:13 — cf8498d

팔 초기값 측정을 ② 카드 바로 다음으로 옮김 (③ 안전 설정보다 앞)

기존엔 팔 인식 모드 카드 안(③ 안전 설정보다도 뒤, 손 굽힘 표시 섹션
다음)에 있어서, 손가락 초기값 측정 직후 이어서 팔 초기값까지 측정하려면
안전 설정 카드를 거쳐 스크롤해야 했다. 팔 초기값 측정을 독립된 카드로
빼서 ② 초기값 측정(손가락) 바로 다음, ③ 안전 설정보다 앞에 배치.

행동 보조 모드도 이 값이 있어야 실행되므로(actionCalibrationReady),
이 카드는 팔 인식 모드뿐 아니라 행동 보조 모드에서도 보이게 함 --
기존엔 행동 보조 모드에서 이 값이 없으면 어디서 측정해야 하는지
안내만 있고 카드 자체는 팔 인식 모드에 가야만 보였던 것도 같이 해결됨.

Co-Authored-By: Claude Sonnet 5 <noreply@anthropic.com>

---

### 2026-09-16 20:15 — 40e7748

행동 보조 모드에서 ⑤ 카드의 TARGET/ACTUAL/제어 패널 숨김

이 패널(TARGET/ACTUAL/오차 + 제어 시작/해제 버튼 + 판단 상태)은 거울
모드/팔 인식 모드가 실제로 쓰는 공용 controlEnabled 플로우를 보여주는
건데, 행동 보조 모드는 자기만의 실행 버튼/폐루프를 따로 쓰고 이
플로우를 전혀 안 써서 행동 보조 모드에서는 항상 대기중/0으로 고정돼
있었다. 방금 추가한 손/팔꿈치 큰 칸과 헷갈릴 수 있어 행동 보조 모드일
땐 이 패널만 숨기고(기록 로그는 모든 모드 공용이라 계속 보여줌).

Co-Authored-By: Claude Sonnet 5 <noreply@anthropic.com>

---

### 2026-09-16 20:48 — fa894ee

수저 들기 보조: 손/팔꿈치 동시 진행으로 되돌리고, 전체 속도 3배 증가

손이 먼저 목표에 도달해야 팔꿈치로 넘어가던 순차 진행을, 실제 수저
드는 동작은 손을 쥐는 것과 팔꿈치를 드는 게 동시에 일어나야 자연스럽다는
피드백에 따라 다시 동시 진행으로 되돌림 -- 손/팔꿈치 둘 다 매 tick
목표를 향해 같이 움직이고, 각자 도달하면 그 축만 유지하다가 둘 다
도달하면 완료 처리(정지)한다. "도달해도 전류 안 멈추던" 이전 버그와
같은 종류의 문제가 재발하지 않게, 완료 조건도 그때와 동일한 방식으로
처리.

속도는 config.control.controlPeriodMs를 2250 -> 750(실제 주기
900ms -> 300ms)으로 줄여서 3배 빠르게 함 -- maxStep(1씩 점진적으로
오르는 것)은 그대로 둬서 "부드럽게 세는" 느낌은 유지. 이 값이 전역
설정이라 팔 인식 모드/이두운동에도 동일하게 적용됨.

Co-Authored-By: Claude Sonnet 5 <noreply@anthropic.com>

---

### 2026-09-16 21:06 — 19909e2

테스트 모드 채널1/채널2 세기 기본값을 100으로 변경

Co-Authored-By: Claude Sonnet 5 <noreply@anthropic.com>

---

### 2026-09-16 21:50 — 13139f8

CSV 다운로드를 시행(trial) 기준 요약으로 재설계

예전엔 카메라 프레임마다 한 줄씩(수천 줄) 그대로 CSV로 내보내서 사람이
"몇 번 시도해서 몇 번 성공했는지" 알아보기 어려웠다. 이제 목표에
도달(LOCKED)할 때마다 1회 성공으로 기록하고, 12초 안에 도달 못하면
그 시도를 실패로 기록한 뒤 바로 다음 시도 관찰을 시작한다
(updateTrialTracking, controlEnabled로 실제 목표를 쫓는 동안만 관찰 --
거울 모드/팔 인식 모드에서 동작, 둘 다 공용 controlState를 씀).

CSV에는 맨 위에 요약(총 시행/성공/실패/성공률/평균 도달 시간)을 넣고,
그 아래 시행별 결과(번호/성공-실패/도달 시간/목표%/실제%/시각)를 한
줄씩, 그 아래에 참고용으로 원본 tick 로그를 이어 붙인다. 엑셀에서 한글
안 깨지게 BOM도 추가. "데이터 기록" 카드에 도달 시도/성공 실시간
카운터도 추가.

Co-Authored-By: Claude Sonnet 5 <noreply@anthropic.com>

---

### 2026-09-16 21:50 — 6164db2

"개인화 캘리브레이션 (선택)" 카드 화면에서 숨김

관련 JS가 참조하는 DOM을 남겨두기 위해 완전히 지우지 않고
display:none으로 숨김 (손가락별 목표 vs 실제 표를 숨긴 것과 동일한 방식).

Co-Authored-By: Claude Sonnet 5 <noreply@anthropic.com>

---

### 2026-09-16 21:54 — ea9218c

행동 보조 모드: 회원번호 시스템 제거, 설정을 컴퓨터 공용으로 저장

회원번호별로 목표%를 따로 저장하던 방식(loadMembers/saveMembers,
emsWebMembers)을 없애고, 이 컴퓨터에서 마지막으로 저장한 값 하나만
기억하는 방식(loadActionSettings/saveActionSettings, emsWebActionSettings)
으로 바꿨다. 수저 들기 보조/이두운동 각 섹션에 자기 목표%(/반복 횟수)만
저장하는 "저장" 버튼을 추가(saveActionInputs) -- 페이지를 새로 열면
applyStoredActionSettings()가 자동으로 다시 채운다.

개인화 측정(finishPersonalizationCal)도 이제 회원번호 없이 바로 이
저장소에 handIntensity/elbowIntensity를 기록하고, 실행 시 웜스타트로
쓰는 seedActionAxisCtrls(구 seedActionAxisCtrlsFromMember)도 같은
저장소를 본다. 회원번호/이름 입력칸, 불러오기/등록 버튼, 관련 안내
문구를 전부 제거.

Co-Authored-By: Claude Sonnet 5 <noreply@anthropic.com>

---

### 2026-09-16 21:57 — b1d4860

거울 모드: 컵 잡기/따르기/흔들기 등 미리 정의된 행동 버튼 제거 + 실시간 왼손 연동 타겟 표시 버그 수정

- 컵 잡기/따르기 동작/흔들기 동작/팔 굽히기/물건 놓기 버튼(ACTIONS 배열,
  buildActionButtons/selectAction)을 제거. 전부 실측 데이터가 아닌
  placeholder 목표값이었고, 거울 모드는 실시간 왼손 연동 하나로 충분하다고
  판단. selectedActionText/actionDescriptionText는 실시간 왼손 연동
  전용 상태 표시로 재활용(대기 중 / 연동 중).

- ⚠ 버그 수정: "실시간 왼손 연동 시작"을 눌러도 targetPercent 갱신
  (updateLiveMirrorTarget)이 controlEnabled(=▶ 제어 시작을 누른 상태)
  분기 안에서만 실행되고 있어서, 연동을 시작해도 제어 시작까지 눌러야
  TARGET 값이 나왔다. 실제 전기자극은 여전히 제어 시작을 눌러야 나가는
  게 맞지만, 목표값 표시는 연동 시작 즉시 나오도록 controlEnabled=false
  분기에서도 updateLiveMirrorTarget()을 호출하게 수정.

Co-Authored-By: Claude Sonnet 5 <noreply@anthropic.com>

---

### 2026-09-16 21:58 — 7aabfde

행동 보조 모드: 이두운동/수저 들기 보조 섹션·버튼 순서 교체

id는 그대로 두고 화면에 나타나는 순서만 바꿔서(이두운동 -> 수저 들기
보조, 실행 버튼도 이두운동 -> 수저 들기 보조 순), 기능은 전혀 손대지
않음.

Co-Authored-By: Claude Sonnet 5 <noreply@anthropic.com>

---

### 2026-09-16 22:05 — cbc2278

음성 명령을 "탱글이" 이름 부르는 항상 켜짐 방식 음성 비서로 재설계

기존엔 버튼 누를 때마다 한 문장만 인식하고 "수저들기보조"/"이두운동"
정확히 두 단어만 알아들었다. 이제 마이크 버튼을 한 번 켜면 계속 듣는
상태가 되고(continuous 인식 + onend에서 자동 재시작), "탱글아"/
"탱그라"라고 부르면 "네"라고 대답한다.

이름을 부른 뒤 10초(VOICE_AWAKE_WINDOW_MS) 동안만 명령을 받아들이는
"깨어있는 시간" 개념을 추가 -- 실제 사람 몸에 전기자극을 내보내는
기능이라, 이름을 부르지 않은 채 흘러가는 일상 대화(예: "나 밥 먹었어")
에 그냥 반응하면 안전하지 않다고 판단해서 넣은 안전장치. 사용자가 물어본
그대로("나 밥먹고싶어", "나 밥먹는거 도와줘", "수저들기 보조해줘" 등)는
전부 인식하되, 이 안전 게이트 뒤에서만 동작한다.

- "수저들기 보조" 계열 문구 -> 지금 앱이 어떤 모드에 있든 행동 보조
  모드로 전환 후 수저 들기 보조 바로 실행.
- "이두운동해줘" -> "몇 회 하시겠어요?"로 되묻고, 숫자(아라비아 숫자
  또는 한글 숫자 1~10)로 답하면 그 반복 횟수로 설정해서 바로 실행.

버튼은 그대로 두되 라벨/의미를 "마이크 켜기/끄기"(항상 듣기 온오프)로
바꿈. 관련 HTML 안내 문구도 새 동작에 맞게 수정.

Co-Authored-By: Claude Sonnet 5 <noreply@anthropic.com>

---

### 2026-09-16 23:21 — fefe99d

음성 비서: 항상 듣기 자동 시작 + 오른쪽 위 상태 표시 + AI(Gemini) 자연어 인식

- 페이지를 열면 마이크 버튼을 안 눌러도 자동으로 "항상 듣는" 상태로
  시작한다(toggleVoiceCommand()를 init에서 한 번 호출). 버튼은 끄고
  싶을 때 쓰는 수동 온오프 용도로 남겨둠.
- 화면 오른쪽 위에 항상 떠 있는 작은 표시(voiceListenIndicator) 추가 --
  "듣고 있음" / "탱글이가 듣고 있어요(깨어있음)" / "몇 회인지 대답해주세요"
  상태를 어느 모드/카드에 있든 항상 보여준다. awake 상태가 10초 뒤
  저절로 풀리는 것도 반영되게 0.5초마다 갱신.
- 정해진 문구(수저/숟가락/밥먹고싶/밥먹는거/이두)로 못 잡은 발화는,
  API 키가 입력돼 있으면 Gemini에게 보내 "수저 들기 보조/이두운동/
  둘 다 아님" 중 뭘 원하는지 판단시킨다(classifyVoiceIntentWithAI --
  옛 거울 모드의 interpretCommandWithAI()와 같은 REST 직접 호출 +
  responseSchema로 JSON 강제하는 패턴 재사용). "나 배고파", "팔 운동
  좀 하고싶어" 같은 표현도 이제 인식됨. 음성 비서 카드에 API 키 입력칸
  추가(비어있으면 정해진 문구만 인식, 기존 aiConfig 저장소 재사용).

Co-Authored-By: Claude Sonnet 5 <noreply@anthropic.com>

---

### 2026-09-16 23:26 — 3422ca6

버그 수정: 페이지 로딩이 도중에 멈춰서 모드 버튼이 전혀 안 눌리던 문제

원인: 마이크 자동 시작 코드(if (SpeechRecognitionCtor) toggleVoiceCommand();)
가 파일 앞쪽(초기화 구간)에서 실행되는데, toggleVoiceCommand()가 참조하는
voiceEnabled/voiceAwakeUntil/voicePendingBicepReps는 파일 훨씬 뒤쪽(음성
비서 섹션)에 let으로 선언돼 있었다. 이 자동 시작 호출 시점엔 아직 그
선언부에 도달하지 못했으므로 TDZ(Temporal Dead Zone)에 걸려 "Cannot
access before initialization" 오류가 그 자리에서 던져졌고, 이 오류가
잡히지 않은 채로 스크립트 전체 실행이 그 줄에서 멈춰버렸다 -- 그
뒤에 나오는 모드 선택 버튼을 포함한 모든 addEventListener 등록 코드가
실행되지 못해 화면의 모든 버튼이 먹통이 됐던 것.

voiceEnabled/voiceAwakeUntil/voicePendingBicepReps/VOICE_AWAKE_WINDOW_MS
선언을 voiceRecognition과 같이 파일 맨 위(자동 시작 호출보다 앞)로
옮겨서 해결. node --check는 문법만 보고 이런 실행 순서 문제는 못 잡아서
발견이 늦었음 -- 이후 비슷한 자동 실행 코드를 앞쪽에 추가할 때는 거기서
참조하는 let/const가 전부 그보다 앞에 선언돼 있는지 직접 확인 필요.

Co-Authored-By: Claude Sonnet 5 <noreply@anthropic.com>

---

### 2026-09-16 23:34 — 2927ee5

이두운동: 수축(굽힘) 완료될 때마다 횟수를 소리로 세줌

굽힘(curl) 단계가 목표에 도달하는 순간을 "1회"로 세고, 유지/이완까지
기다리지 않고 그 즉시 speak()로 "N회"라고 읽어준다(로그/토스트에도 남김).
"수축완료가 1회 기준"이라는 요청대로, 유지+이완이 끝나야 세는 게 아니라
굽힘 자체가 완료되는 시점 기준으로 카운트.

Co-Authored-By: Claude Sonnet 5 <noreply@anthropic.com>

---

### 2026-09-16 23:35 — ab10a6a

음성 비서: AI 호출 실패 시 화면 글자뿐 아니라 소리로도 알려줌

Gemini가 503(과부하)/네트워크 오류 등으로 응답 실패하면 이전엔 로그에만
남고 사용자에게는 아무 반응이 없어서 왜 조용한지 알기 어려웠다.
classifyVoiceIntentWithAI가 null(호출 실패)을 반환하면 speak()로도
안내하도록 수정 (AI가 정상적으로 "관련 없음"이라고 판단한 경우와는
구분해서, 실패했을 때만 이 안내가 나감).

Co-Authored-By: Claude Sonnet 5 <noreply@anthropic.com>

---

### 2026-09-16 23:39 — b3f7fb9

음성 비서: 한 번 명령 수행 후 "탱글아"를 다시 불러도 반응 없던 문제 수정

브라우저 음성 인식 세션이 (특히 speak()로 응답한 뒤) 조용히 끊기는
경우가 있는데, 그 직후 onend에서 바로 부르는 재시작(start())이 타이밍
문제로 실패하면 그냥 조용히 포기하고 있었다 -- 그러면 voiceEnabled는
여전히 true인데 실제 인식 세션은 죽어있는 상태가 돼서, 마이크를 껐다
켜야만(다시 start() 호출) 원래대로 돌아왔다.

voiceSessionActive(세션이 실제로 살아있는지)를 onstart/onend로 추적하고,
0.5초마다 도는 watchdog(watchVoiceSession)이 "켜져 있어야 하는데 세션이
안 살아있는" 상태를 보면 계속 재시작을 시도하게 만들어 스스로 복구되도록
수정. 정상 작동 중일 땐 watchdog이 아무것도 안 해서 평소엔 조용하다.

Co-Authored-By: Claude Sonnet 5 <noreply@anthropic.com>

---

### 2026-09-16 23:52 — 76877f1

음성 비서: 수저/이두 둘 다 아니면 그냥 대화형 AI처럼 대답하게 확장

classifyVoiceIntentWithAI의 판단 결과에 "chat" 액션을 추가 -- 수저 들기
보조/이두운동과 무관한 말(저녁 메뉴 추천, 잡담, 일반 질문 등)이면 전기
자극은 실행하지 않고 AI가 만든 대답(reply)을 speak()로 그대로 읽어준다.
같은 AI 호출 한 번으로 "행동 실행 판단"과 "일반 대화 응답"을 동시에
처리(액션 분류 스키마에 reply 필드 추가). 대화가 자연스럽게 이어지도록
chat 응답 후에도 깨어있는 시간(10초)을 연장.

Co-Authored-By: Claude Sonnet 5 <noreply@anthropic.com>

---

### 2026-09-17 00:29 — d1aa10e

이두운동 굽힘 유지 시간 1초 -> 0.5초로 변경

Co-Authored-By: Claude Sonnet 5 <noreply@anthropic.com>

---

### 2026-09-17 00:34 — 995b13e

팔 인식 정확도 개선: pose 모델 lite -> full, 카메라 해상도 640x480 -> 1280x720(ideal)

두 가지가 팔 인식 각도 오차의 주요 원인으로 보여서 같이 손봤다.
1) PoseLandmarker가 빠르지만 덜 정확한 "lite" 모델을 쓰고 있었다 --
   pose_landmarker_full.task(공식 MediaPipe 모델)를 새로 받아서 교체.
   손 인식(hand_landmarker)과 맞춰 minPoseDetectionConfidence/
   minPosePresenceConfidence/minTrackingConfidence도 0.7로 설정.
2) 카메라 해상도가 640x480이라, 손 하나만 잡을 땐 충분해도 어깨~손목까지
   화면에 다 들어와야 하는 팔 인식에서는 관절 하나하나가 차지하는
   픽셀 수가 너무 적어 각도 오차가 컸다. 1280x720(ideal)로 올림 --
   canvas 크기는 이미 video.videoWidth/videoHeight를 그대로 따라가게
   되어 있어서 추가 수정 없이 자동으로 커짐. 이 해상도를 지원 안 하는
   웹캠이면 자동으로 가능한 해상도로 낮아짐(ideal이라 실패하지 않음).

손 인식은 그대로 hand_landmarker.task(원래도 정확도 높은 모델)를 계속
쓰므로 영향 없음 -- 이번엔 팔 쪽만 정확도를 올림.

Co-Authored-By: Claude Sonnet 5 <noreply@anthropic.com>

---

### 2026-09-17 00:37 — b28e0bf

이두운동: 굽힘 유지 단계 완전히 제거 -- 도달하면 바로 이완으로

수축(굽힘) 완료 즉시(유지 없이) 이완 목표로 넘어가도록 변경. 관련
BICEP_CURL_HOLD_MS 상수/holdStartedAt 상태/"hold" 단계를 전부 정리하고
안내 문구도 맞춰 수정.

Co-Authored-By: Claude Sonnet 5 <noreply@anthropic.com>

---

### 2026-09-17 00:44 — 06bab09

이두운동: 수축이 목표 이상 되면 LOCKED 기다리지 않고 바로 이완으로 전환

기존엔 굽힘 단계가 허용범위 안에서 successHoldSeconds만큼 버텨야 하는
LOCKED 상태가 돼야 이완으로 넘어갔는데, 이제 실제 굽힘 %가 목표치에
도달하거나 넘어서는 즉시(armLatestPercent.actual >= elbowCurlTarget)
바로 이완으로 전환한다.

Co-Authored-By: Claude Sonnet 5 <noreply@anthropic.com>

---

### 2026-09-17 00:49 — 969b2b8

이두운동: 이완도 목표 이하 되면 LOCKED 기다리지 않고 바로 다음 단계로

굽힘->이완 전환과 같은 방식으로, 이완 단계도 실제 %가 목표치에 도달하거나
그 이하가 되는 즉시(LOCKED 대기 없이) 다음 반복(굽힘) 또는 완료 처리로
넘어가도록 수정.

Co-Authored-By: Claude Sonnet 5 <noreply@anthropic.com>

---

### 2026-09-17 00:53 — cbd4689

이두운동: 지정 횟수 다 끝나면 "완료되었습니다"를 음성으로 안내

Co-Authored-By: Claude Sonnet 5 <noreply@anthropic.com>

---

### 2026-09-17 01:03 — fc19baf

행동 보조 모드에서 "개인화 측정(목표 도달 세기 자동 탐색)" 기능 완전히 제거

요청대로 이 기능 전체(HTML 카드/버튼/입력칸, JS 상태·함수 전부)를 지웠다.
이 기능의 유일한 소비처였던 웜스타트(seedActionAxisCtrls)와 "저장된 세기"
안내 문구(spoonLiftSeedText/bicepSeedText)도 더 이상 채워질 값이 없어져
같이 정리 -- 이제 수저 들기 보조/이두운동 실행은 항상 0부터 자동으로
세기를 찾는다. saveActionInputs/applyStoredActionSettings도 이제 목표%
(/반복 횟수)만 다루도록 단순화.

Co-Authored-By: Claude Sonnet 5 <noreply@anthropic.com>

---

### 2026-09-17 01:05 — 18a0768

오른손/오른팔을 카메라가 놓쳤을 때 걸리던 비상정지 제거

runtimeCheck()에서 handLost 조건을 제거 -- 이제 손/팔을 놓쳐도 완전
비상정지는 안 걸린다. 시리얼 연결 끊김/연속 자극 시간 초과/전체 실험
시간 초과는 그대로 비상정지 사유로 남아있음. 손을 놓친 동안은 각 모드
컨트롤러가 WAITING_FOR_HAND로 표시하며 목표 추적만 잠깐 멈추는 기존
동작은 그대로 유지(강제 정지는 아님).

Co-Authored-By: Claude Sonnet 5 <noreply@anthropic.com>

---

### 2026-09-17 01:09 — 577e334

음성 비서: "N회" 발음이 어색하던 문제 수정 -- 숫자를 한글로 풀어서 읽게 함

"이두운동 3회를 시작합니다"처럼 숫자+회를 그대로 speak()에 넘기면
브라우저 한국어 TTS가 숫자와 단위 사이를 어색하게 끊어 읽는 경우가
있었다. sinoKoreanNumber()로 숫자를 한글 한자어 수사로 변환해서
("이두운동 삼회를 시작합니다") 훨씬 자연스럽게 읽히도록 수정 -- 시작
안내와 매 회차 카운트 음성 둘 다 적용.

Co-Authored-By: Claude Sonnet 5 <noreply@anthropic.com>

---

### 2026-09-17 01:10 — 5bd1847

음성 비서: 일반 대화 응답이 너무 길게 나오던 것 -- 짧은 한 문장으로 제한

"운동을 모두 마치셨군요... 필요하신 게 있으면 말씀해주세요" 처럼 뒤에
인사치레/추가 제안이 붙어 길어지던 문제. 시스템 프롬프트에서 "딱 핵심만
담은 한 문장, 뒤에 덧붙이는 말 금지"로 명확히 제한.

Co-Authored-By: Claude Sonnet 5 <noreply@anthropic.com>

---

### 2026-09-17 01:12 — 8144e37

이두운동 횟수 완료 팝업을 5배 크게 표시

showToast에 big 옵션 추가(.toast.big -- 글자 크기 14px -> 70px, 패딩/
테두리도 맞춰서 키움). 다른 토스트(경고/오류 등)는 기존 크기 그대로 두고
이두운동 회차 완료 알림에만 적용. 커진 글자를 읽을 시간을 조금 더 주려고
표시 시간도 1.5초 -> 1.8초로 살짝 늘림.

Co-Authored-By: Claude Sonnet 5 <noreply@anthropic.com>

---

### 2026-09-17 01:32 — 033a195

"전체 실험 제한시간" 기능 완전히 제거

③ 카드의 "전체 실험 제한시간 (초)" 입력칸/"⏱ 타이머 초기화" 버튼/남은
시간 표시(pill)와, 그 뒤의 강제 정지 로직(totalTimeExceeded, runtimeCheck/
spoonLiftTick/bicepClosedLoopTick에서의 체크)을 전부 제거. config.safety.
totalExperimentSeconds/experimentStart도 정리.

⑤ 카드의 "경과 시간" 표시는 그대로 남겨뒀다 -- 이건 카메라를 처음 켠
뒤 얼마나 지났는지 보여주기만 하는 참고용이고 아무것도 강제로 멈추지
않아서, 요청하신 "제한시간" 기능과는 별개로 판단(sessionStartedAt으로
이름을 바꿔 그 표시 전용으로만 남김).

Co-Authored-By: Claude Sonnet 5 <noreply@anthropic.com>

---

### 2026-09-17 09:52 — c7b5318

손 좌우 뒤집기 체크박스와 팔 좌우 뒤집기 체크박스를 하나로 동기화

카메라가 좌우로 뒤집혀 보이는 원인은 손/팔이 따로가 아니라 카메라 자체
하나라서, 둘 중 아무 체크박스나 누르면 나머지 하나도 같은 상태로 같이
바뀌게(체크박스 표시 + 실제 값 invertHandedness/invertArmSides 둘 다)
동기화. 매번 두 군데 다 따로 체크할 필요 없어짐. 안내 문구도 서로
연결되어 있음을 명시하도록 수정.

Co-Authored-By: Claude Sonnet 5 <noreply@anthropic.com>

---

### 2026-09-17 10:26 — 8aeea9c

버그 수정 2건: 목표 0에서도 전류 안 꺼지던 문제 / 테스트 모드 정지 지연 문제

1) stepFlexOnlyAxis(팔 인식/행동 보조 공용)와 updateController(거울 모드)
   둘 다, 목표(targetPercent)가 거의 0인데 실제 굽힘도 마침 그 근처라서
   허용오차 안에 들어오면 "목표 도달 -- 유지" 분기를 타면서 그 순간까지
   남아있던 세기를 그대로 "유지"해버렸다. 목표가 낮아져서 0이 된 상황도
   이 분기로 들어가는데, 그러면 유지할 자세가 없는데도 전류가 안 꺼지는
   문제였다. 목표 자체가 허용오차 이하로 낮으면 세기를 0으로 내리도록 수정.

2) 테스트 모드에서 카메라를 켜둔 채 방향키를 뗐을 때 전류가 바로 안
   끊기던 문제 -- 최근 "거울 모드 제외 전부 팔 인식" 요청과 Pose 모델
   lite->full 교체(+해상도 상향)가 겹치면서, Pose 추론이 메인 스레드를
   붙잡는 시간이 길어져 정지(세기 0) 시리얼 명령이 밀려 늦게 나가는
   원인이 됐다. 테스트 모드는 "즉시 정지"가 핵심이라 팔 인식(참고용
   표시일 뿐이었음)을 이 모드에서만 다시 뺐다 -- 손 스켈레톤은 그대로
   보임. 팔 인식 모드/행동 보조 모드는 그대로 유지.

Co-Authored-By: Claude Sonnet 5 <noreply@anthropic.com>

---

### 2026-09-17 10:47 — e674394

음성 비서: 식사 관련 말 들으면 바로 실행하지 않고 "실행할까요?" 되물음

"밥먹고싶어" 등 수저 들기 보조 관련 발화(정해진 문구든 AI 판단이든)를
들으면 바로 실행하지 않고 "수저 들기 보조를 실행할까요?"라고 한 번
되묻는다. "응"/"네"/"예"/"해줘"/"실행"/"시작" 등 긍정으로 대답하면
그때 실행하고, 아니면(또는 시간 초과) 실행하지 않고 취소.
이두운동의 "몇 회 하시겠어요?" 되묻기와 같은 패턴(isAffirmative 헬퍼로
긍정 여부 판단).

Co-Authored-By: Claude Sonnet 5 <noreply@anthropic.com>

---

### 2026-09-17 13:34 — ff84c19

fix: 팔 인식/행동 보조 모드에서 목표가 낮아져도 전기가 안 줄어들던 문제 수정

stepFlexOnlyAxis가 세기를 내릴 때도 올릴 때와 똑같이 300ms 주기에 1씩만
내려가서, 실시간으로 계속 바뀌는 목표(왼손/반대팔 연동)가 훅 낮아져도
액추얼이 한동안 목표보다 훨씬 높은 채로 남아 전기가 계속/더 세지는 것처럼
보였다. 세기를 낮추는 건 안전 문제가 없으므로, 내려갈 때는 주기 제한 없이
매 프레임 훨씬 빠르게(reduceKp/reduceMaxStep) 따라가도록 분리했다. 거울모드
updateController()의 kpDown/maxStepDown(신전 채널 게인)은 건드리지 않았다.

Co-Authored-By: Claude Sonnet 5 <noreply@anthropic.com>

---

### 2026-09-17 16:21 — 66d6007

fix: 행동 보조 모드에서 팔 인식 모델 첫 추론 워밍업 비용을 로딩 단계로 이동

pose_landmarker_full.task(+720p)로 정확도를 올린 뒤로 첫 detectForVideo()
호출에서 WASM 추론 커널이 그제서야 준비(JIT)돼 몇 초씩 걸렸는데, 이 비용이
이두운동을 막 시작한 시점의 실제 프레임에 그대로 나가서 "초반엔 팔 엑추얼
값이 측정 안 됨"으로 보였다. ensurePoseLandmarker()가 모델을 만든 직후
빈 캔버스로 한 번 미리 detectForVideo를 호출해 그 워밍업 비용을 로딩
토스트가 떠 있는 준비 단계에서 대신 치르게 했다.

Co-Authored-By: Claude Sonnet 5 <noreply@anthropic.com>

---

### 2026-09-18 11:29 — 7a46b8d

docs: 최종 시연 문서/케이스 설계/초기 프로토타입 정리 (포트폴리오 이관용)

- 기존 PDF 보고서 3개를 docs/로 이동, 전시판넬 PDF·설계정리 docx·재활보조
  시스템 보고서·시연 시 패치 위치 사진을 docs/에 추가
- 발표 구술 초안을 정리해 docs/시연_대본_및_QA.md 작성 (신경가소성 정의 채워
  넣기, 근거 부족한 ±5% 수치는 일반화, 부정확하다고 지적된 표현은 대체 문구로
  교체, 확인이 필요한 메모는 별도 섹션으로 남김)
- 보드 케이스 3D 프린팅 설계(STL)와 조립 영상을 hardware/case/에 추가
- 현재 구조 이전의 초기 하드웨어 프로토타입(피드백 장갑, 주먹 버튼 테스트)을
  archive/early_prototypes/에 개발 히스토리로 보존
- README의 폴더 구조 표/안전 설정 설명을 지금 코드 기준(4모드, 연속자극
  60초, 전체 실험 제한시간 없음)으로 갱신

Co-Authored-By: Claude Sonnet 5 <noreply@anthropic.com>

---

### 2026-09-18 11:39 — e7d114a

docs: 파일별 설명 문서 추가 및 여는 방법 안내 최신화

- 파일_설명.txt 신규 추가: app.js/index.html/*.task 등 최상위 파일과
  docs·hardware·firmware·archive 등 폴더가 각각 무슨 역할인지 비개발자도
  이해할 수 있게 정리
- 열기_안내.txt가 구버전 ems_demo_standalone.html을 "추천 방법"으로
  안내하고 있던 걸, 지금 최종본인 index.html(run_server.bat)이 방법 1이
  되도록 순서를 바꾸고 구버전 한계를 명시

Co-Authored-By: Claude Sonnet 5 <noreply@anthropic.com>

---

### 2026-09-18 11:41 — 26e34d4

cleanup: 구버전 스냅샷/standalone 데모/미사용 lite 모델 삭제

저장소 목적이 "최종 기록/포트폴리오"로 정해지면서, 실제로는 안 쓰는 구버전
사본들이 계속 헷갈림을 줄 뿐이라는 피드백에 따라 정리:

- mediapipehand/ (2026-08-23 구버전 스냅샷 전체) 삭제
- ems_demo_standalone.html (위 구버전을 파일 하나로 번들링한 데모) 삭제
- pose_landmarker_lite.task (full 모델로 교체된 뒤 코드에서 안 쓰던 파일) 삭제

README.md/파일_설명.txt/열기_안내.txt에서 위 항목을 안내하던 부분도 함께
정리. 필요하면 git 히스토리(예: 이 커밋의 부모)에서 언제든 복원 가능.

Co-Authored-By: Claude Sonnet 5 <noreply@anthropic.com>

---

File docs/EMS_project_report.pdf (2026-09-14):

# 파일을 찾을 수 없음

제거 또는 삭제되었을 수 있습니다.

ERR_FILE_NOT_FOUND

Microsoft Edge

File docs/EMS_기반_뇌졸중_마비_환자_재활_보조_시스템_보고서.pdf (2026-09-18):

## 제 22회 공학경진대회 예비 심사 보고서

## 1. 작품 제목

EMS 기반 뇌졸중·마비 환자 재활 보조 시스템

## 2. 작품 개요

최근 고령화와 뇌졸중·마비 발생률 증가로 인해, 편마비 환자를 비롯한 상지 기능 장애 환자들의 재 활치료 수요가 지속적으로 늘어나고 있다. 그러나 기존 재활치료는 치료사의 상시 개입과 반복적인 훈련이 필요해 인력과 시간의 한계가 존재한다.

뇌졸중 환자는 뇌의 한쪽 운동 영역 손상으로 반대쪽 손의 움직임이 둔해지는 편마비가 흔히 나타난 다. 본 작품은 비교적 정상적으로 움직이는 손의 동작을 기준으로, 마비된 손의 해당 근육에 EMS 자 극을 주어 동일한 동작을 재현하는 폐루프 시스템과, 음성 명령으로 필요한 동작을 지시하면 회원별 로 개인화된 자극값을 즉시 적용하는 동작 보조 시스템으로 구성된다.

이를 통해 환자가 목표 동작을 직접 확인하며 마비된 손에서도 같은 움직임을 반복할 수 있고, 이때 발생하는 근육 수축과 감각 피드백이 뇌로 전달되어, 뇌가 반복된 경험을 통해 새로운 신경 연결을 형성하며 손상된 부위의 기능을 대신하도록 돕는 신경가소성 과정을 촉진한다.

## 3. 작품의 주요 기능

1. 비전 기반 폐루프 동작 재현

카메라 영상만으로 손가락 관절의 위치를 실시간으로 인식하는 손 인식 기술 MediaPipe를 활용해, 한쪽 손의 손가락 굽힘 정도를 측정해 목표값으로 설정하고, 반대쪽 팔에 EMS 자극을 가한 뒤 카메 라로 재측정한 실제 굽힘값과 목표값의 오차를 계산해 자극 세기를 자동으로 보정한다. 오차가 일정 범위 이내로 수렴하면 자극을 즉시 차단해 과도한 자극을 방지한다.

2. 회원별 개인화 프리셋 관리

사용자마다 부여된 회원번호(ID)에, 해당 사용자에게 필요한 동작(예: 이두운동)과 자극 세기, 세트 수 등 개인화된 설정값을 저장할 수 있다. 이후 회원번호를 입력하면 저장된 개인 맞춤 설정값이 자동 으로 불러와져, 매번 값을 재설정할 필요 없이 사용자에게 맞는 자극을 즉시 적용할 수 있다.

3. 음성 명령 기반 동작 보조

물리적 조작 없이도, 사전에 등록된 특정 동작(그립, 팔꿈치 굽힘 등)을 음성 명령만으로 즉시 실행할 수 있도록 보조하는 기능이다. 사용자가 등록된 동작명을 음성으로 말하면 이를 인식하여, 음성으로 실행 시작을 안내한 뒤 사전에 등록된 자극 세기값으로 동작을 수행한다. 이는 손 사용이 어려운 사

용자도 별도의 조작 없이 필요한 동작을 즉각적으로 수행할 수 있도록 지원해 접근성을 높인다.

4. 안전장치

안전 최대 자극값 제한, 비상정지 기능을 갖추어 시스템 오류나 사용자의 이상 반응 시 즉시 자극을 차단할 수 있도록 하였다.

## 4. 현재 개발 상황 및 개발 계획

현재 개발 상황

- 2채널 EMS 장비(TENS 7000, OpenEMSstim 펌웨어 기반)를 이용해 그립(주먹쥐기, 파지) 동작 및 이에 수반되는 팔꿈치 굽힘(이두운동, 수저 들기 보조) 동작 구현을 완료하고, 실제 팔에 전기자극 을 가하는 하드웨어 테스트를 완료함.
- MediaPipe 기반 양손 인식 및 손가락별 굽힘률 계산, 목표 동작 설정(캡처 및 자연어 명령) 기능 을 구현함.
- 안전 최대값, 비상정지 등 안전장치를 구현 및 검증함.
- 전극 부착 위치가 안정적으로 확보된 경우 목표 오차범위(±5%) 내 수렴을 반복적으로 확인함.
- 오차 기반 폐루프 제어 로직을 여러 차례의 튜닝을 통해 안정화함.

향후 개발 계획

단기 계획

- 개인마다 다른 근육 위치와 자극 반응을 반영하기 위해, 여러 세기의 자극을 순차적으로 주고 실 제 반응을 측정해 개인별 반응 모델을 만드는 개인화 캘리브레이션 기능을 실측 검증 후 정식 적용 할 예정.
- AI 기반 자연어 명령 해석 기능을 도입하여, 자유로운 문장(예: "식사 보조해줘", "이두운동해줘")으 로 명령해도 의도를 해석해 안전 범위 내에서 채널별 자극값과 동작 순서를 자동으로 구성하도록 확 장할 계획이며, 이를 통해 지원 동작의 종류를 늘리고 기존 동작도 더 자연스럽게 다듬을 예정.
- 안정적인 전극 고정 방법 검토.
- 손떨림 보정 기능 향후 확장 검토.

장기 계획

- 다채널 시스템으로 확장하여 손가락별 정밀 제어와 개인별 근육 반응을 반영한 맞춤형 제어로 발 전시킬 계획.
- 장치의 소형화·무선화 추진.
- 단계적인 사용자 검증을 거쳐, 장기적으로 실제 재활 현장에 적용 가능한 시스템으로 발전시키는

것을 목표로 함.

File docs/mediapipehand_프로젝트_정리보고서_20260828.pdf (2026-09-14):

# MediaPipeHand — AI 비전 피드백 폐루프 EMS 제어 시스템

프로젝트 진행 내용 정리 보고서

대상 경로: C:\Users\brigh\OneDrive\바탕화면\mediapipehand\ | 작성일: 2026-08-28 | Claude Code 소스 분석 기반 자동 정리

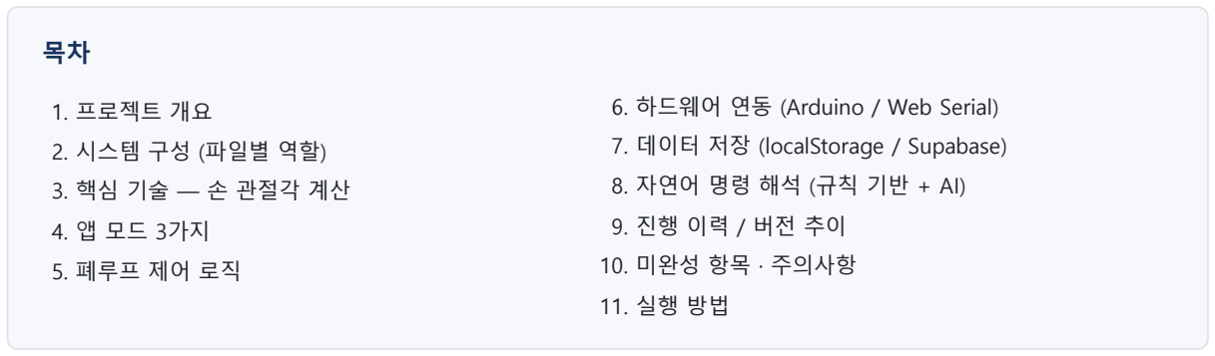
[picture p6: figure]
1. 프로젝트 개요; 2. 시스템 구성 (파일별 역할); 3. 핵심 기술 — 손 관절각 계산; 5. 폐루프 제어 로직; 6. 하드웨어 연동 (Arduino / Web Serial); 7. 데이터 저장 (localStorage / Supabase); 8. 자연어 명령 해석 (규칙 기반 + AI); 10. 미완성 항목 · 주의사항

### 1. 프로젝트 개요

이 프로젝트는 MediaPipe Hand Landmarker(손 관절 인식) 기반 컴퓨터 비전과 EMS(전기근육자극, Electrical Muscle Stimulation) 하드웨어(Arduino 연동)를 결합한 AI 비전 피드백 폐루프(closed-loop) 제어 데모 시스템입니다.

"왼손으로 원하는 동작을 만들어 캡처(스냅샷)하면 그게 목표가 되고, 오른손(EMS 연결 대상)이 카메라로 측정되며 그 목표에 가까워지도록 EMS 제어값(0~100)이 자동 조절됩니다." — index.html:185-198

왼손(SOURCE / TARGET) — 목표 동작을 지정하는 손 (카메라로만 인식, EMS 패치 없음)
오른손(ACTUAL) — 실제 EMS 자극이 가해지는 손 (카메라로 측정 + 전기자극 인가)

카메라가 두 손의 손가락 굽힘 정도를 실시간 측정 → 목표와 실제의 오차 계산 → 비례제어(P control)로 EMS 출력 자 동 조절 → 목표 도달 시 자동 정지/유지되는 구조입니다.

UI의 사전정의 동작이 "수저 들기 보조", "이두운동(재활/보조)" 등인 점, 참가자별 개인화 반응 곡선을 저장하는 "회원번 호" 시스템, "참가자 프로필(Supabase)" 용어 등으로 미루어 손 움직임에 제약이 있는 사용자를 위한 EMS 기반 손동작 보조·재활 연구 프로토타입으로 추정됩니다. 코드 내 "교수님이 말씀하신 '사용자별 근육 반응 학습'"(app.js:2816) 주석 으로 볼 때 지도교수가 있는 학부/대학원 연구 과제(캡스톤 혹은 관련 프로토타입)로 보이며, 자연어/AI(Gemini) 명령 해 석까지 실험적으로 결합한 것으로 보아 "AI 비전 + 자연어 인터페이스 + 폐루프 EMS 제어" 통합 검증이 목적으로 판단 됩니다.

### 2. 시스템 구성

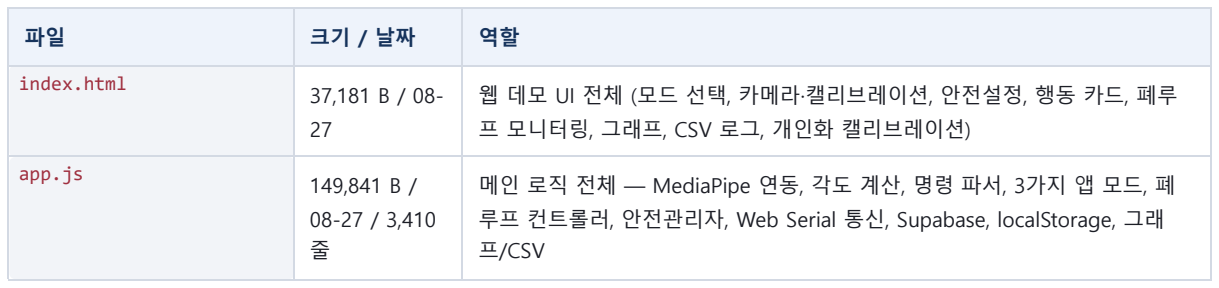
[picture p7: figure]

index.html | 37,181 B / 08-27 | 웹 데모 UI 전체 (모드 선택, 카메라·캘리브레이션, 안전설정, 행동 카드, 폐루 프 모니터링, 그래프, CSV 로그, 개인화 캘리브레이션)
app.js | 149,841 B / 08-27 / 3,410 줄 | 메인 로직 전체 — MediaPipe 연동, 각도 계산, 명령 파서, 3가지 앱 모드, 폐 루프 컨트롤러, 안전관리자, Web Serial 통신, Supabase, localStorage, 그래 프/CSV
26. 8. 28. 오전 12:33 | MediaPipeHand — AI 비전 피드백 폐루프 EMS 제어 시스템 정리 보고서
file:///C:/Users/brigh/.claude/jobs/e5a30cf9/tmp/mediapipehand_summary.html | 1/6

hand_camera.py | 6,044 B | OpenCV+MediaPipe 파이썬 프로토타입 — 웹캠으로 5손가락 굽힘각을 실시 간 표시 (EMS 연동 없음, app.js 각도식의 원형)
hand_landmarker.task | 7.8 MB | MediaPipe 손 랜드마크 인식 모델 (Python 버전용 로컬 모델; 웹 버전은 CDN 로드)
run_server.bat | 142 B | python -m http.server 8000 로컬 정적 서버 실행 배치파일
ems_demo_standalone.html | 10.5 MB / 08-24 | 더 오래된 초기 버전을 하나의 파일로 번들링한 독립 실행형 데모. 인식 모델 을 base64로 내부 임베드해 서버 없이 열 수 있으나, 인식 엔진 JS는 여전히 CDN에서 로드 (완전 오프라인 아님)
mediapipehand\ (내부 폴 더) | 08-23 | 더 이전 개발 단계의 구버전 스냅샷 (3번 참고)

⚠ 발견된 문제 — 기존 PDF 산출물 손상
폴더에 있던 EMS_project_report.pdf 와 EMS_폐루프_제어_시스템_개발기록.pdf 두 파일은 바이트 단위로 완전히
동일하며, 실제 보고서 내용이 아니라 "파일을 찾을 수 없음 (ERR_FILE_NOT_FOUND)" 브라우저 오류 화면을 그 대로 인쇄(Print to PDF)한 결과물입니다. PDF 메타데이터의 Creator가 HeadlessChrome/Edg 151 로 찍혀 있어, 이 전에 헤드리스 브라우저로 요약 페이지를 PDF화하려다 파일 경로 인코딩 문제로 실패한 결과로 추정됩니다. 즉 두 파일은 사실상 빈 문서이며 이번에 이 보고서로 대체됩니다.

### 3. 핵심 기술 — 손 관절각 계산

Python(hand_camera.py)과 JS(app.js) 양쪽에 동일한 공식이 구현되어 있습니다.

3D 관절각 계산

MediaPipe의 world landmarks(손목 기준 실제 3D 좌표, 미터 단위)를 사용
세 점 A(기준)–B(중심 관절)–C(다음 관절)에 대해 벡터 v1=A−B, v2=C−B의 내적/코사인으로 사이각 계산

angle = acos(clip(v1·v2/(|v1||v2|), -1, 1)) (도 단위 변환)
굽힘량 = 180 − angle (편 상태 ≈180°→굽힘 0°), 음수는 0으로 클램프
손가락 1개당 관절 3개의 굽힘량 합산, 0~270도로 클램프

웹 버전(app.js)은 엄지를 제어에서 제외합니다 — CMC 관절 구조가 달라 동일 공식이 정확하지 않기 때문 (app.js:38-51). 제어(Index/Middle/Ring/Little 4손가락)와 표시 전용(엄지 포함 5손가락)을 명확히 분리했습니다.

노이즈 완화

Python 버전: deque(maxlen=5) 단순 이동평균 (5프레임)
JS 버전( MedianEmaFilter , app.js:224-244): 최근 5프레임의 중앙값을 구한 뒤 지수이동평균(EMA, α=0.35) 적용 — 순간적 튐(outlier)에 더 강건

% 환산은 캘리브레이션(펴짐/구부림) 값 대비 선형 보간이며, 오른손 기준 캘리브레이션을 왼손 값 환산에도 재사용합 니다(두 손 유연성이 비슷하다는 가정).

### 4. 앱 모드 3가지

원래 "거울 모드"가 왼손 캡처/명령/프리셋 카드였으나, 사용자 요청으로 해당 UI를 제거하고 "행동 보조 모드"가 그 역 할 일부를 흡수하는 형태로 재구성되었습니다. 3개 모드는 상호 배타적이며, 전환 시 이전 모드의 모든 제어를 강제로 0 정지시켜 채널 충돌을 방지합니다.

file:///C:/Users/brigh/.claude/jobs/e5a30cf9/tmp/mediapipehand_summary.html | 2/6

① 거울 모드 (mirror) — 폐루프

행동 버튼(컵 잡기 / 따르기 / 흔들기 / 팔 굽히기 / 물건 놓기)으로 사전정의 목표 % 로드 실시간 왼손 연동: 매 프레임 왼손 현재 굽힘값을 그대로 오른손 목표로 계속 갱신 전송 카메라 오차 보정이 있는 폐루프 방식

② 행동 보조 모드 (action) — 오픈루프

"채널1/채널2에 직접 입력한 고정 전류를 오픈루프로 출력 (카메라 오차 보정 없음)" — index.html:230-231

수저 들기 보조: 채널1 2초 램프업 → 채널2 3초 램프업, 순차 유지
이두운동: 채널1은 2초 램프 후 유지, 채널2는 "3초 상승→1초 유지→3초 하강→0.5초 휴식"을 지정 횟수 반복 회원 개인화: 회원번호로 채널1/채널2/반복횟수를 localStorage에 저장·불러오기
음성 명령: Web Speech API로 "수저들기보조"/"이두운동" 두 단어만 인식해 바로 실행

③ 개인화 모드 (personalization) — 수동 램프업

"선택한 채널의 전류를 서서히 올리다가 키보드 'A'로 정지 (역치/반응 확인용)" — index.html:232-233

별도로 개인화 캘리브레이션(자동 스윕) 기능이 있어, 20/40/60/80/100 등 여러 자극값을 순서대로 자동으로 주고 실제 반응(% 굽힘)을 측정해 개인별 선형회귀 모델을 만듭니다. (SWEEP_HOLD_MS=4000ms 유지, SWEEP_REST_MS=2500ms 휴식, SWEEP_RESEND_MS=900ms 재전송 주기)

전체 상태값: STANDBY / IDLE / WAITING_FOR_HAND / INCREASING / DECREASING / HOLDING / SUCCESS / LOCKED / SAFETY_STOP / SWEEP_HOLD / SWEEP_REST

### 5. 폐루프 제어 로직

핵심 함수: updateController(currentPercent, now) — app.js:2490-2574
오차: error = targetPercent − currentPercent
허용범위 내(±tolerancePercent, 기본 5%): 마지막 세기를 계속 유지(연속 출력). successHoldSeconds(기본 1.5초) 이 상 유지되면 LOCKED(도달 완료) 전환, 해제 버튼 전까지 자극 유지
오차 큼: controlPeriodMs(기본 6000ms, ÷2.5=2400ms) 주기로만 비례(P) 제어 스텝 계산 — 매 프레임 전송 시 시리 얼 큐 적체로 지연되는 문제가 실측되어 스로틀 처리
2채널 방향 라우팅: error>0(덜 구부러짐)→채널1(굴근), error<0(더 구부러짐)→채널2(신근). 채널 전환 시 0부터 재 램프업(길항근 동시자극 방지)
게인: kpUp=0.02(채널1, 조심스럽게 증가) / kpDown=0.3(채널2, 빠르게 회수) / maxStepUp=1 / maxStepDown=8 내부 작업값은 float로 누적 — 정수 반올림 시 미세 증가분이 사라져 목표 근처서 멈추는 버그 방지 controllerIntensity(0~100)는 config.safety.maxIntensity로 클램프 후 하드웨어 전송; 화면엔 클램프 전/후 값을 분리 표시

안전 / 워치독

runtimeCheck(): 시리얼 연결 끊김, 오른손 놓침(연속 10프레임 미검출), 연속 자극시간 초과(기본 10초), 전체 실험 시간 초과(기본 300초=5분, 카메라 켠 시점부터 카운트) 감시
비상정지: ESC/SPACE 키, 화면 비상정지 버튼, 브라우저 탭 백그라운드 전환 시 자동 트리거 safetyTripped: 한 번 트립되면 "안전 정지 해제" 버튼 누르기 전까지 모든 모드가 즉시 재차단됨
LOCKED 상태: 일반은 6초 간격 전송이지만 LOCKED(유지)일 땐 400ms 간격으로 촘촘히 재전송
file:///C:/Users/brigh/.claude/jobs/e5a30cf9/tmp/mediapipehand_summary.html | 3/6

### 6. 하드웨어 연동 (Arduino / Web Serial)

class WebSerialLink (app.js:3040-3223) — Web Serial API로 Arduino와 텍스트 프로토콜 통신.

Baud rate: 19200
연결 절차: requestPort() → open → 2초 대기(보드 리셋 안정화) → PING 최대 3회 재시도, PONG 대기(핸드셰이크) → 성공 시 400ms마다 백그라운드 PING(연결 유지)

명령 프로토콜: ARM,<ch> / SET,<ch>,<intensity>,<durationMs> / STOP,<ch> / STOP_ALL
TTL 기반 재전송: SET 명령에 duration(TTL, 기본 1500ms, 최대 5000ms)을 실어 보내 자극 끊김 방지. 지속 출력 필 요 시 900ms 등 짧은 주기로 재전송
채널 전환 안전장치: 채널 변경 시 새 채널을 켜기 전 이전 채널을 명시적으로 0 OFF 전송
브라우저 요구사항: Chrome 또는 Edge (미지원 시 연결 버튼 비활성화)

### 7. 데이터 저장

localStorage (브라우저/컴퓨터 로컬)

키 | 내용
emsWebConfig | 프리셋/제어 게인/안전값/시리얼 설정
emsWebCalibration | 펴짐/구부림 캘리브레이션(손가락별 각도)
emsWebAdaptiveModel | 로그 기반 자동 회귀 모델(slope/intercept)
emsWebPersonalization | 개인화 스윕 결과 점들 + 회귀계수
emsWebAiConfig | AI(Gemini) 사용 여부/API 키/모델명
emsWebMembers | 회원번호별 채널1/채널2/반복횟수
emsWebParticipantId | Supabase 참가자 ID 캐시

Supabase 클라우드 (calibration_profiles 테이블)

URL/anon key가 app.js 상단에 하드코딩되어 있습니다. 코드 주석에서 명시적으로 리스크를 밝힙니다:

"anon key는 클라이언트에 노출돼도 되는 공개 키입니다 (RLS 정책으로 접근 범위를 제한). 로그인 없이 참가자 ID 문자열 하 나로만 구분하는 프로토타입 구조라, 같은 ID를 아는 사람은 그 데이터를 읽고 덮어쓸 수 있다는 점은 감안하세요." — app.js:17-19

목적은 참가자가 다른 컴퓨터/브라우저로 옮겨도 캘리브레이션·개인화 데이터를 이어서 쓸 수 있게 하는 것입니다. 현재 상태: 관련 함수는 코드에 남아있지만, 이를 쓰는 UI 카드(참가자 프로필)와 이벤트 바인딩은 "나중에 다시 추가할 예 정"으로 전부 주석 처리되어 비활성화된 상태입니다.

### 8. 자연어 명령 해석

규칙 기반 (rule-based) — 현재 비활성 UI

interpretCommand(text) (app.js:259-298) — command_interpreter.py를 JS로 포팅, LLM 미사용.

정지어(정지/멈춰/스탑/stop), 종료어(종료/끝내/quit/exit) 처리 "NN%"/"NN퍼센트"/"NN프로" 정규식 직접 지정

file:///C:/Users/brigh/.claude/jobs/e5a30cf9/tmp/mediapipehand_summary.html | 4/6

프리셋 매칭: 살짝/조금만→light, 최대한/세게→strong, 반쯤/절반→half

AI(Gemini) 경로 — 현재 비활성 UI

interpretCommandWithAI(text) (app.js:1492-1599) — 브라우저에서 Google Gemini API 직접 호출(백엔드 서버 없음), 기본 모델 gemini-3.7-flash.

responseSchema로 JSON 강제 출력(action/target_percent/message)
"탁구공을 쥘 정도로" 같은 비유도 크기/모양 추론해 % 값으로 매핑하도록 프롬프트 설계
API 키는 브라우저 localStorage에만 저장, 이 컴퓨터에서 직접 Gemini API로 전송
호출 실패/키 없음/파싱 실패 시 항상 규칙 기반으로 조용히 대체(fallback)

현재 상태: 이 두 경로와 관련 UI 카드(캡처/명령입력/프리셋) 전체가 index.html/app.js에서 통째로 주석 처리되어 현재 화면상 사용 불가합니다. 함수 자체는 남아있어 주석만 해제하면 복구 가능하도록 설계되어 있습니다.

### 9. 진행 이력 / 버전 추이

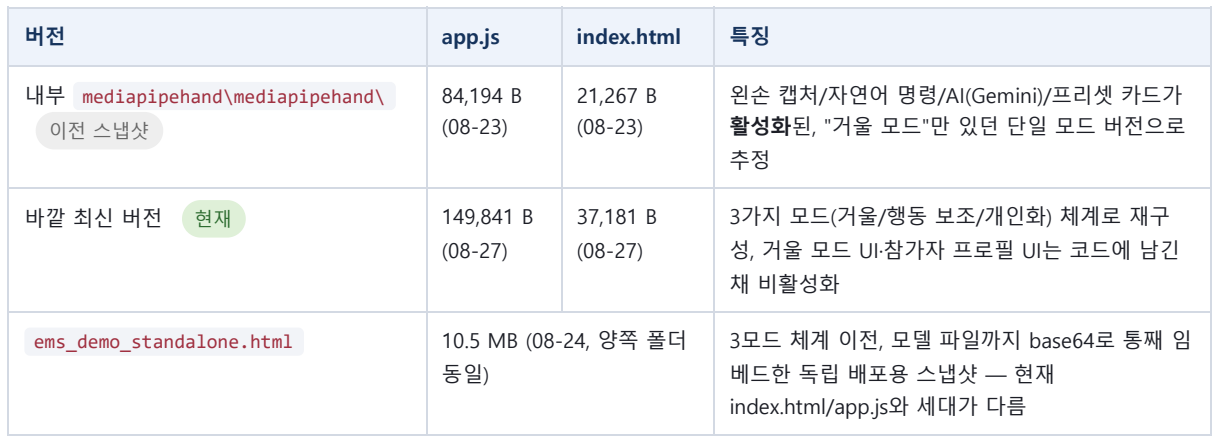
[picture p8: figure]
app.js; index.html

내부 mediapipehand\mediapipehand\ 이전 스냅샷 | 84,194 B (08-23) | 21,267 B (08-23) | 왼손 캡처/자연어 명령/AI(Gemini)/프리셋 카드가 활성화된, "거울 모드"만 있던 단일 모드 버전으로 추정
바깥 최신 버전 현재 | 149,841 B (08-27) | 37,181 B (08-27) | 3가지 모드(거울/행동 보조/개인화) 체계로 재구 성, 거울 모드 UI·참가자 프로필 UI는 코드에 남긴 채 비활성화
ems_demo_standalone.html | 10.5 MB (08-24, 양쪽 폴더 동일) | | 3모드 체계 이전, 모델 파일까지 base64로 통째 임 베드한 독립 배포용 스냅샷 — 현재 index.html/app.js와 세대가 다름

변경 이력은 코드 주석이 스스로 설명하고 있습니다:

"예전 '거울 모드'(왼손 캡처/자연어 명령/프리셋/AI 해석) -- 사용자 요청으로 제거하고 '행동 보조 모드'가 새 '거울 모드'가 됨. 통째로 주석 처리해서 보관, 나중에 필요하면 이 주석만 풀면 그대로 복구된다." — index.html:329-332

"참가자 프로필(Supabase)은 나중에 다시 추가할 예정이라 지금은 UI에서 뺐습니다 (app.js에 관련 함수는 남겨둠)." — index.html:223-224

### 10. 미완성 항목 · 주의사항

1. 행동 버튼 목표값이 전부 placeholder — 컵 잡기 55%, 따르기 45%, 흔들기 60%, 팔 굽히기 70%, 물건 놓기 5% 등 은 실측이 아닌 임시 수치. 손가락별 개별 목표(targetPerFinger)는 전부 null로 미구현.
2. 캘리브레이션이 컴퓨터/브라우저 간 공유 안 됨 — localStorage 기반이라 새 컴퓨터마다 펴짐/구부림 재측정 필요. Supabase로 해결 시도했으나 현재 비활성.
3. Arduino 물리 연결 필요 — 실제 전기자극 테스트는 USB 연결 필수 (기본은 연결 없이도 시뮬레이션 동작).
4. Supabase anon key 노출 — 클라이언트에 하드코딩, RLS만으로 접근 제한 (개발자가 스스로 캐비어트 명시).
5. Web Serial API 브라우저 제약 — Chrome/Edge만 지원, 로컬 서버(run_server.bat) 구동 권장.
6. 연속 자극 자동정지 제한(기본 10초) — LOCKED 유지 중에도 자주 걸리므로 필요시 사람이 직접 값 조정 필요.
7. 모드별 총 소요시간이 전체 안전 제한(5분)을 넘을 수 있음 — 경고는 하지만 강제로 막지는 않음.
file:///C:/Users/brigh/.claude/jobs/e5a30cf9/tmp/mediapipehand_summary.html | 5/6

8. 거울 모드 관련 UI 전부 비활성화 — 자연어 명령/AI 해석/왼손 캡처/프리셋/참가자 프로필 카드가 현재 사용 불가.
9. 이두운동 하강/휴식 시간이 임의 결정 — "명시 요구사항이 없어 상승 시간과 대칭(3초)/짧은 휴식(0.5초)으로 우선 설정, 필요시 값 조정 가능"이라고 코드 주석에 명시.
10. kpDown 게인 재튜닝 필요 가능성 — 채널2가 실제로 펴는 근육을 담당하게 되며 설계 의도와 달라져, 실제 반응을 보고 재조정이 필요할 수 있음.
11. 기존 PDF 산출물 손상 — EMS_project_report.pdf / EMS_폐루프_제어_시스템_개발기록.pdf 두 파일 모두 내용 없이 브라우저 오류 페이지만 인쇄되어 있었음 (본 보고서로 대체).

### 11. 실행 방법

방법 1 (추천, 설치 없이 바로 열기)

ems_demo_standalone.html 더블클릭 → Chrome/Edge로 열기. 인터넷 연결 필요(인식 엔진 온라인 로드), 카메 라/Arduino(USB 시리얼) 권한 허용. 단, 이 파일은 08-24 시점 구버전(단일 거울 모드) 스냅샷이므로 최신 3모드 버전이 아닙니다.

방법 2 (최신 버전 — index.html/app.js — 사용 시 필요)

1. Python 설치 (python.org, "Add to PATH" 체크)
2. run_server.bat 더블클릭 → "로컬 서버를 http://localhost:8000 에서 실행합니다" 확인
3. 브라우저에서 http://localhost:8000 접속
4. 종료 시 검은 창에서 Ctrl+C

공통 주의사항

처음 여는 컴퓨터라면 카메라 펴짐/구부림 초기값(캘리브레이션)을 다시 측정해야 함 실제 전기자극 테스트에는 Arduino가 그 컴퓨터에 USB로 연결되어 있어야 함

Claude Code가 프로젝트 소스코드(app.js, index.html, hand_camera.py 등)를 직접 읽어 정리한 보고서입니다. · 2026-08-28

file:///C:/Users/brigh/.claude/jobs/e5a30cf9/tmp/mediapipehand_summary.html | 6/6

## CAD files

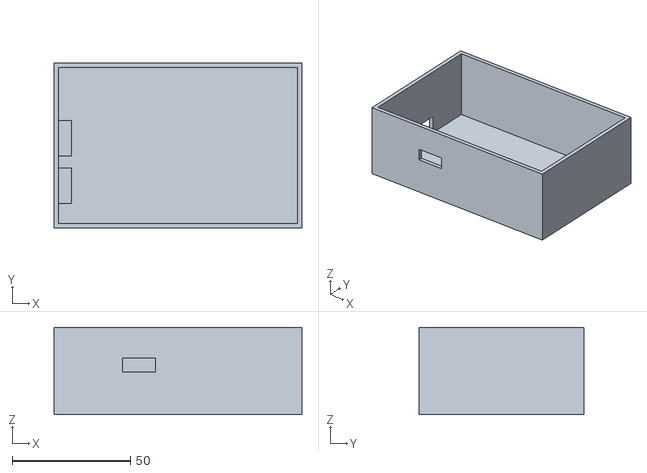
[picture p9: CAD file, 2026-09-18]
hardware/case/emsboardcase (2).stl
105.0 x 70.0 x 37.0

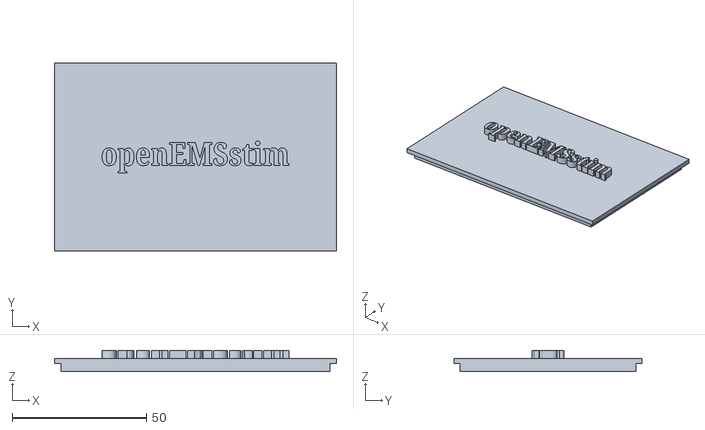
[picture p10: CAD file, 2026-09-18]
hardware/case/뚜껑.stl
105.0 x 70.0 x 8.00

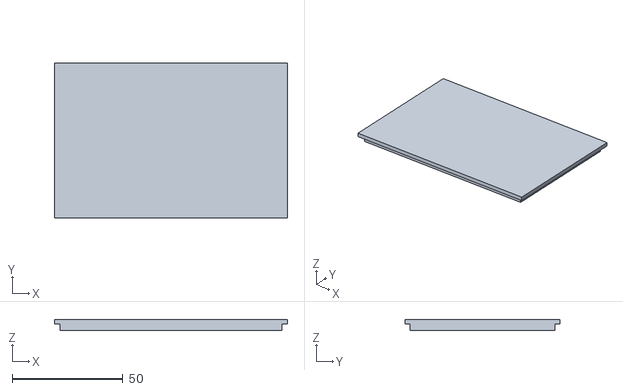
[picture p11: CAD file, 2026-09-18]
hardware/case/emsboardcase (1).stl
105.0 x 70.0 x 5.00

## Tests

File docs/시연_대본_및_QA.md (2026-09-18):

# 📋 시연 대본 및 예상 질문 (Q&A)

한성공학경진대회 16번 팀 — EMS 재활 보조 시스템 최종 시연용 대본입니다.
아래 대본은 실제 발표 중 구술한 초안을 정리한 것이며, 본문 중 부정확하다고
스스로 지적한 수치·표현은 [수정] 표시와 함께 정리했습니다.

---

## 시연 시작

"시연 시작하겠습니다."

---

## ■ 1. 거울 모드

**[행동]** 거울 모드 진입 → 카메라 실행

### ① 초기값 측정
사람들마다 손가락을 다 폈을 때의 초기값이 다를 수 있기 때문에, 펴짐·구부림
초기값을 측정합니다.

### ② 안전 설정
다음으로는 안전 설정 단계입니다. 안전 최대 제어값을 설정하여 과한 전류가
흐르지 않게 합니다. 연속 자극 시간도 제한하여 근육의 부담을 줄여줍니다.

### ③ 연결 및 연동
아두이노를 연결합니다. 왼손의 구부림 값을 측정하기 위해 실시간 왼손 연동을
시작합니다.

### ④ 제어 시작
그 후 제어 시작을 누르게 되면, 왼손의 구부림 정도에 따라 오른손이
구부러지게 됩니다.

> 💬 (오디오가 비었을 때 부가 설명)
> 패치를 붙이지 않은 손을 구부리면, 패치를 붙인 손이 그 값을 따라가기 위해
> 전류를 공급합니다. 오차가 허용 범위 안으로 들어오면 전류 증가를 멈춥니다.
> 반대로 손을 펴게 되면, 손을 펴는 근육에 붙어 있는 패치에 전기가 흘러
> 원래 상태로 되돌아오게 됩니다. 이때 목표값에 가까워질수록 EMS 제어값이
> 올라가는 정도를 줄여주어, 목표에 조금 더 정확하게 도달할 수 있게 합니다.

### ⑤ 강조 포인트
버튼이나 다른 입력이 아닌 본인의 반대 손의 동작을 가져오기 때문에,
신경가소성 측면에서 기존의 재활 방식보다 좋습니다.

> 여기서 신경가소성이란, 경험·학습·환경 변화 또는 뇌 손상에 반응하여 뇌가
> 스스로 신경 회로와 구조를 재조직하고 변화시키는 능력을 말합니다.

**[행동]** 패치 위치 변경 → 주먹 쥐기, 이두

---

## ■ 2. 팔 인식 모드

### ① 초기값 측정
다음으로는 팔 인식 모드입니다. 앞에서 손의 초깃값은 측정하였지만 팔은
측정하지 않았기 때문에, 팔의 초기값도 측정합니다.

### ② 제어 시작
제어 시작을 누르면 시작됩니다. 팔을 구부리면 그에 따라 오른팔이
구부러지게 되고, 이 상태로 손을 구부리게 되면 손도 서서히 구부러지게
됩니다. 목푯값에 도달하게 되면 전기자극을 유지하고, 과하게 수축하게 되면
전류를 줄여 목표와 가까워질 때까지 피드백을 반복합니다.

### ③ 강조 포인트
앞선 거울 모드와 크게 다르지 않은 기능이지만, 예산적 여유가 되어 채널만
늘릴 수 있다면 일상생활에 필요한 대부분의 동작을 구현할 수 있다는 것을
강조하고 싶어, 두 개의 채널로 할 수 있는 다양한 동작을 보여드리기 위해
노력했습니다.

---

## ■ 3. 행동 보조 모드

### ① 소개
다음으로는 행동 보조 모드를 설명해드리겠습니다. 이 프로젝트는 편마비
환자를 주된 대상으로 제작되었기 때문에, 음성 인식을 통해 재활을 하는 데
용이하게 하였습니다. (초기값은 앞에서 설정했으므로 생략)

이 부분의 주된 기능은 음성 인식을 이용하고 Gemini API를 사용하여, 음성을
받아 원하는 동작을 수행하는 기능입니다.

### ② 이두운동 (음성 시연)

```
나:   탱글아
탱글: 네
나:   이두 운동 해줘
탱글: 몇 회 할까요?
나:   3회 해줘
탱글: 이두운동 3회를 시작합니다.
```

**[수행 중]**

> 💬 (오디오가 비었을 때)
> 목표값인 80에 도달하게 되면, 다시 이완을 위해 목표값이 20으로
> 재설정됩니다. 이를 반복해 이두운동을 수행합니다.

```
탱글: 1회, 2회, 3회 완료되었습니다.
```

**[행동]** 패치 이동 → 이두 가운데와 팔꿈치 쪽으로

### ③ 식사 보조 (버튼 시연)
다음으로는 마지막 동작으로, 비교적 간단한 동작이지만 일상에서 필수적인
식사 보조 동작을 보여드리겠습니다. 음성 인식으로도 가능하지만 앞서
보여드렸기 때문에, 버튼으로 신속하게 시연하겠습니다.

**[수행 중]** — 수저 들기 보조

수저 들기 보조 동작이 특별한 동작은 아니지만, 뇌졸중 환자의 대부분은
완전한 마비가 아니라 어느 정도 움직임이 남아있는 경도 마비 환자가 더
많기 때문에, 완전한 동작을 대신 수행해주는 것보다는 약한 전기 자극을 통해
원래 하고자 하는 동작을 보조하는 데 도움을 줄 수 있어 간단하지만 매우
중요한 동작이라 프로젝트에 넣었습니다.

---

## ■ 마무리

**[행동]** 추가 질문에 대비해 잠시 시간 벌기

---

## 배경 설명 자료 — 기존 치료법과의 차별점

> 발표 준비 중 정리한 배경 지식입니다. 시연 대본 본문보다는 심화 질문이나
> 강조 포인트를 보충 설명할 때 참고용으로 씁니다.

### 1. 기존 거울치료(Mirror Therapy)와의 차별점
- **기존 거울치료의 한계**: 거울을 보며 움직임을 상상하게 하지만, 실제
  마비된 근육은 멈춰 있어 "시각은 움직였다고 인지하나 고유수용감각은 멈춰
  있는 감각 불일치(Sensory Mismatch)"가 발생해 뇌 자극 효율이 떨어짐.
- **본 시스템의 차별화**
  - 시각과 체성감각의 완전 일치: 정상 손을 관찰하는 시각 자극과 마비 손의
    실제 근육 수축(EMS) 감각을 실시간 동기화하여 감각 불일치 해소.
  - 반구 간 억제 완화: 정상 손의 능동적 동작과 마비 손의 전기 자극을 동시에
    진행하는 양측성 훈련(Bilateral Training) 효과로, 손상된 뇌 반구를
    억누르는 비정상적 억제 현상 개선.
  - 거울신경세포계(MNS)의 물리적 완성: 시각적 착각에만 머물던 기존
    치료와 달리, 실제 운동 실행 피드백을 결합해 신경망 재조직화를 가속.

### 2. 뇌파 연동 FES(BCI-FES)와의 차별점
- **기존 BCI 치료의 한계**: "움직이겠다"는 뇌파를 감지하는 원리는 우수하나,
  뇌파 캡 착용, 젤 도포, 잡음 보정 등 세팅이 지나치게 복잡해 신경가소성의
  필수 조건인 '매일 고빈도 반복 훈련(High Dosage)'이 불가능.
- **본 시스템의 차별화**
  - 운동 의도의 직관적 대체: 복잡한 뇌파 장비 대신 '음성 명령(Top-down
    의도)'과 '정상 손의 움직임'을 운동 의도의 대리 지표로 활용.
  - 전두엽 운동 계획 활성화: 환자가 직접 음성으로 동작을 발화하는 과정에서
    브로카 영역과 전운동 피질(운동 계획 루프)을 사전 흥분(Priming) 유도.
  - 압도적인 훈련 접근성: 일반 웹캠과 경량 보드 기반으로 제작되어, 환자
    혼자서도 즉시 훈련을 시작할 수 있어 반복 훈련량을 극대화.

### 3. 소뇌 기반 오차 수정 학습(Error-based Motor Learning)과의 차별점
- **기존 수동 자극의 한계**: 일반 EMS나 고정형 FES는 관절이 얼마나 펴졌는지와
  무관하게 타이머대로 자극만 주는 '오픈루프(Open-loop)' 방식이라, 뇌(소뇌)가
  오차를 인지하지 못해 운동 학습 회로가 작동하지 않음.
- **본 시스템의 차별화**
  - 비전 기반 폐루프(Closed-loop) 제어: MediaPipe로 정상 손(목표)과 마비
    손(실측)의 관절각 오차를 실시간 계산하고, 비례(P) 제어로 자극 세기를
    보정하여 오차를 줄여나감.
  - 뇌의 오차 수정 회로 완벽 모사: 오차가 허용 범위 안으로 수렴하면
    안정화되는 구조를 통해, 뇌가 스스로 오차를 줄이며 시냅스를 강화하는
    '소뇌의 운동 학습 기전'을 기계적으로 실현.

> **[수정 반영]** 원본 초안에는 이 항목의 허용 오차를 "±5%"로 못 박아
> 두었으나, 시행 횟수가 적어 그 수치 자체를 확신할 근거가 부족하다는
> 자체 지적이 있어 구체적인 수치는 빼고 "허용 범위"로 일반화했습니다.
> 실제 값을 밝히고 싶다면 충분한 반복 시행으로 재검증한 뒤 채워 넣으세요
> (코드상 기본값은 `config.control.tolerancePercent = 5`입니다).
>
> **[표현 주의]** "신경가소성에서 뇌가 스스로 손상된 기능을 대신한다"는
> 표현은 과학적으로 부정확하다는 지적이 있었습니다. 신경가소성의 정확한
> 정의는 위 거울 모드 ⑤ 강조 포인트에 채워 넣은 문장("경험·학습·환경 변화
> 또는 뇌 손상에 반응하여 뇌가 스스로 신경 회로와 구조를 재조직하고
> 변화시키는 능력")을 그대로 쓰고, "손상된 기능을 대신한다"는 식의 표현은
> 쓰지 않는 것을 권장합니다.

---

## 예상 질문 (Q&A)

**Q. 왜 EMS를 사용했나요?**
전기자극으로 실제 근육을 수축시켜 움직임을 만들 수 있기 때문입니다. 특히
저희는 움직임을 측정하고 자극 세기를 다시 조절하는 폐루프 제어를 구현하기
위해 EMS를 사용했습니다.

**Q. 기존 FES·재활기기와 차이점은 무엇인가요?**
전기자극으로 움직임을 만든다는 점은 유사합니다. 저희 시스템의 핵심
차별점은 정상 손을 목표값으로 사용하고, 마비된 손의 실제 움직임을 측정해
자극 세기를 실시간으로 자동 보정하는 폐루프 제어입니다.

---

## ⚠ 확인 필요 (미해결 메모)

대본 원본 끝에 아래 메모가 남아 있었는데, 어떤 문서(발표 슬라이드/포스터로
추정)를 가리키는지 이 정리 과정에서는 확인할 수 없어 그대로 남깁니다.
발표 전 본인이 직접 확인해 반영해주세요.

- "5 핵심기능 — 사전설정 누락"
- "6번에 구현된 동작에 따르기 << 이거 수정"

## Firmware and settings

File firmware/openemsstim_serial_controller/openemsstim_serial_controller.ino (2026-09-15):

/**
 * openemsstim_serial_controller.ino
 * ----------------------------------
 * PATCH of the official arduino-openEMSstim.ino
 * (https://github.com/PedroLopes/openEMSstim/tree/master/arduino-openEMSstim)
 * that adds a small text-based USB-serial command set (PING/ARM/SET/STOP/
 * STOP_ALL/STATUS) used by serial_link.py, WITHOUT changing any pin wiring,
 * without replacing EMSChannel/EMSSystem/AD5252, and without deleting the
 * original Bluetooth/HEX/single-char command paths (they are still present,
 * just gated behind ENABLE_BLUETOOTH_MODULE in hardware_config.h, which
 * defaults to 0 because this project's prelim explicitly does not use BLE).
 *
 * You still need the original library files sitting next to this .ino,
 * UNCHANGED, exactly as they came from the official repo:
 *   AD5252.cpp / AD5252.h
 *   EMSChannel.cpp / EMSChannel.h
 *   EMSSystem.cpp / EMSSystem.h
 *   AltSoftSerial.cpp / AltSoftSerial.h / AltSoftSerial_Boards.h / AltSoftSerial_Timers.h
 *   Rn4020BTLe.cpp / Rn4020BTLe.h
 *   known_boards.h / known_timers.h
 * (only needed if you set ENABLE_BLUETOOTH_MODULE to 1 -- see hardware_config.h)
 *
 * New USB serial protocol (see README.md for the full spec):
 *   PC -> Arduino : PING | ARM,<ch> | SET,<ch>,<intensity0-100>,<duration_ms> |
 *                   STOP,<ch> | STOP_ALL | STATUS
 *   Arduino -> PC : PONG | ARMED,<ch> | OK,<ch> | STOPPED,<ch> | STATUS,... |
 *                   ERROR,<reason>
 *
 * @license "The MIT License (MIT) - military use of this product is forbidden - V 0.2"
 *  (same license as the original openEMSstim firmware this file patches)
 */

#include "Arduino.h"
#include "hardware_config.h"

#if ENABLE_BLUETOOTH_MODULE
#include "AltSoftSerial.h"
#endif
#include "Wire.h"
#include "AD5252.h"
#if ENABLE_BLUETOOTH_MODULE
#include "Rn4020BTLe.h"
#endif
#include "EMSSystem.h"
#include "EMSChannel.h"
#include "avr/pgmspace.h"

//BT: the string below is how your EMS module will show up for other BLE devices
#define EMS_BLUETOOTH_ID "TEST1"

//DEBUG: setup for verbose mode (prints debug messages if DEBUG_ON is 1)
#define DEBUG_ON 1

//USB: allows commands using the full original protocol (refer to https://github.com/PedroLopes/openEMSstim)
//     kept for reference / BLE-bridge use, OFF by default so it doesn't fight our simple protocol below.
#define USB_FULL_COMMANDS_ACTIVE 0

//USB: allows the original one-char test commands (1,2,q,a,w,s) for quick relay/poti testing.
#define USB_TEST_COMMANDS_ACTIVE 0

//USB: our new PING/ARM/SET/STOP/STOP_ALL/STATUS text protocol used by serial_link.py. ON by default.
#define USB_SIMPLE_PROTOCOL_ACTIVE 1

//helper print function that handles the DEBUG_ON flag automatically
void printer(String msg, boolean force = false) {
  if (DEBUG_ON || force) {
    Serial.println(msg);
  }
}

//Initialization of control objects
//NOTE: pin numbers below are NOT the raw openEMSstim example order anymore --
//they were swapped from the original (5,4,A2)=ch1 / (6,7,A3)=ch2 example
//assignment after LED/멀티미터/사람 테스트로 실제 보드의 채널1 출력이 진짜로
//(6,7,A3) 배선에서 나온다는 게 확인됐기 때문. 보드를 새로 배선했거나 다른
//보드로 바꿨다면 이 확인을 다시 해야 한다 (hardware_config.h 참고).
#if ENABLE_BLUETOOTH_MODULE
AltSoftSerial softSerial;
#endif
AD5252 digitalPot(0);
#if ENABLE_BLUETOOTH_MODULE
Rn4020BTLe bluetoothModule(2, &softSerial);
#endif
EMSChannel emsChannel1(6, 7, A3, &digitalPot, 3);
EMSChannel emsChannel2(5, 4, A2, &digitalPot, 1);
EMSSystem emsSystem(2);

// ---- our patch: simple-protocol state --------------------------------------
bool pcArmed = false;
unsigned long lastHeartbeatPc = 0;

void setup() {
   Serial.begin(SERIAL_BAUD_RATE);
#if ENABLE_BLUETOOTH_MODULE
   softSerial.setTimeout(100);
#endif
   Serial.setTimeout(50);
   printer("\nSETUP:");
   Serial.flush();

#if ENABLE_BLUETOOTH_MODULE
   //Reset and Initialize the Bluetooth module
   printer("\tBT: RESETTING");
   bluetoothModule.reset();
   printer("\tBT: RESET DONE");
   printer("\tBT: INITIALIZING");
   bluetoothModule.init(EMS_BLUETOOTH_ID);
   printer("\tBT: INITIALIZED");
#else
   printer("\tBT: DISABLED (ENABLE_BLUETOOTH_MODULE=0 in hardware_config.h)");
#endif

   //Add the EMS channels and start the control
   printer("\tEMS: INITIALIZING CHANNELS");
   emsSystem.addChannelToSystem(&emsChannel1);
   emsSystem.addChannelToSystem(&emsChannel2);
   EMSSystem::start();
   printer("\tEMS: INITIALIZED");
   printer("\tEMS: STARTED");

   // Safety: every channel starts deactivated (EMSChannel's own constructor
   // already does this via digitalWrite(...LOW), this is an explicit
   // belt-and-suspenders re-assertion).
   emsSystem.shutDown();
   pcArmed = false;

   printer("SETUP DONE (LED 13 WILL BE ON)");
   pinMode(13, OUTPUT);
   digitalWrite(13, HIGH);

   lastHeartbeatPc = millis();
   printer("\tSIMPLE PROTOCOL READY (PING/ARM/SET/STOP/STOP_ALL/STATUS)", true);
}

String command = "";
String hexCommandString;
const String BTLE_DISCONNECT = "Connection End";

void loop() {

#if ENABLE_BLUETOOTH_MODULE
   if (softSerial.available() > 0) {
      String message = softSerial.readStringUntil('\n');
      message.trim();
                printer("\tBT: received command: " + String(message));
      processMessage(message);
                softSerial.flush(); //never tested
   }
#endif

   //Checks whether a signal has to be stoped (millis()-based, non-blocking)
   if (emsSystem.check() > 0) {

   }

   //Communicate to the EMS-module over USB
        if (Serial.available() > 0) {
           if (USB_SIMPLE_PROTOCOL_ACTIVE) {
             String message = Serial.readStringUntil('\n');
             message.trim();
             handleSimpleCommand(message);
           } else if (USB_FULL_COMMANDS_ACTIVE) {
             String message = Serial.readStringUntil('\n');
             printer("\tUSB: received command: " + String(message));
             message.trim();
        processMessage(message);
           } else if (USB_TEST_COMMANDS_ACTIVE) {
             char c = Serial.read();
             printer("\tUSB-TEST-MODE: received command: " + char(c));
        doCommand(c);
      }
          Serial.flush();
   }

   // ---- our patch: PC heartbeat watchdog --------------------------------
   checkHeartbeatWatchdog();
}

// ============================================================================
// ---- our patch: simple PING/ARM/SET/STOP/STOP_ALL/STATUS protocol --------
// ============================================================================

bool isChannelSupported(int channel) {
   if (channel == 1) return CHANNEL_1_ENABLED;
   if (channel == 2) return CHANNEL_2_ENABLED;
   return false;
}

EMSChannel* channelObject(int channel) {
   if (channel == 1) return &emsChannel1;
   if (channel == 2) return &emsChannel2;
   return NULL;
}

void checkHeartbeatWatchdog() {
   if (pcArmed && (millis() - lastHeartbeatPc > (unsigned long) HEARTBEAT_TIMEOUT_MS)) {
      emsSystem.shutDown();
      pcArmed = false;
      printer("\tWATCHDOG: PC heartbeat timeout -> all channels deactivated", true);
   }
}

void handleSimpleCommand(String message) {
   if (message.length() == 0) return;

   // Any well-formed line from the PC counts as a sign of life, not just
   // PING -- a PC that is busy sending SET commands every 500ms should not
   // be treated as silent just because it isn't also sending PING.
   lastHeartbeatPc = millis();

   if (message == "PING") {
      Serial.println("PONG");
      return;
   }

   if (message == "STOP_ALL") {
      emsSystem.shutDown();
      pcArmed = false;
      Serial.println("STOPPED,ALL");
      return;
   }

   if (message == "STATUS") {
      Serial.print("STATUS,armed=");
      Serial.print(pcArmed ? "1" : "0");
      Serial.print(",ch1_active=");
      Serial.print(emsChannel1.isActivated() ? "1" : "0");
      Serial.print(",ch1_intensity=");
      Serial.print(emsChannel1.getIntensity());
      Serial.print(",ch2_supported=");
      Serial.print(CHANNEL_2_ENABLED ? "1" : "0");
      Serial.print(",ch2_active=");
      Serial.print(emsChannel2.isActivated() ? "1" : "0");
      Serial.print(",ch2_intensity=");
      Serial.println(emsChannel2.getIntensity());
      return;
   }

   int firstComma = message.indexOf(',');
   String verb = (firstComma == -1) ? message : message.substring(0, firstComma);

   if (verb == "ARM") {
      int channel = (firstComma == -1) ? -1 : message.substring(firstComma + 1).toInt();
      if (!isChannelSupported(channel)) {
         Serial.print("ERROR,UNSUPPORTED_CHANNEL,");
         Serial.println(channel);
         return;
      }
      pcArmed = true;
      Serial.print("ARMED,");
      Serial.println(channel);
      return;
   }

   if (verb == "SET") {
      // SET,<channel>,<intensity 0-100>,<duration_ms>
      int c1 = message.indexOf(',', firstComma + 1);
      int c2 = (c1 == -1) ? -1 : message.indexOf(',', c1 + 1);
      if (firstComma == -1 || c1 == -1 || c2 == -1) {
         Serial.println("ERROR,BAD_FORMAT");
         return;
      }

      int channel = message.substring(firstComma + 1, c1).toInt();
      int intensity = message.substring(c1 + 1, c2).toInt();
      long duration = message.substring(c2 + 1).toInt();

      if (!pcArmed) {
         Serial.println("ERROR,NOT_ARMED");
         return;
      }
      if (!isChannelSupported(channel)) {
         Serial.print("ERROR,UNSUPPORTED_CHANNEL,");
         Serial.println(channel);
         return;
      }
      if (intensity < 0 || intensity > 100) {
         Serial.println("ERROR,INTENSITY_RANGE");
         return;
      }
      if (duration < 0) duration = 0;
      if (duration > (long) MAX_COMMAND_TTL_MS) duration = MAX_COMMAND_TTL_MS;

      EMSChannel* target = channelObject(channel);
      target->setIntensity(intensity);
      target->setSignalLength((int) duration);
      target->activate();
      target->applySignal(); // sets the millis()-based auto-deactivate deadline; emsSystem.check() in loop() enforces it

      Serial.print("OK,");
      Serial.println(channel);
      return;
   }

   if (verb == "STOP") {
      int channel = (firstComma == -1) ? -1 : message.substring(firstComma + 1).toInt();
      if (!isChannelSupported(channel)) {
         Serial.print("ERROR,UNSUPPORTED_CHANNEL,");
         Serial.println(channel);
         return;
      }
      channelObject(channel)->deactivate();
      Serial.print("STOPPED,");
      Serial.println(channel);
      return;
   }

   Serial.print("ERROR,UNKNOWN_COMMAND,");
   Serial.println(message);
}

// ============================================================================
// ---- original openEMSstim code below, UNCHANGED ---------------------------
// (HEX/BLE command path + single-char test commands. Only reachable if you
//  re-enable ENABLE_BLUETOOTH_MODULE and/or USB_FULL_COMMANDS_ACTIVE /
//  USB_TEST_COMMANDS_ACTIVE above.)
// ============================================================================

//Convert-functions for HEX-Strings "4D"->"M"
char convertToHexCharsToOneByte(char one, char two) {
   char byteOne = convertHexCharToByte(one);
   char byteTwo = convertHexCharToByte(two);
   if (byteOne != -1 && byteTwo != -1)
      return byteOne * 16 + byteTwo;
   else {
      return -1;
   }
}

char convertHexCharToByte(char hexChar) {
   if (hexChar >= 'A' && hexChar <= 'F') {
      return hexChar - 'A';
   } else if (hexChar >= '0' && hexChar <= '9') {
      return hexChar - '0';
   } else {
      return -1;
   }
}

const char ems_channel_1_active[] PROGMEM =    "\tEMS: Channel 1 active";
const char ems_channel_1_inactive[]  PROGMEM = "\tEMS: Channel 1 inactive";
const char ems_channel_2_active[] PROGMEM =    "\tEMS: Channel 2 active";
const char ems_channel_2_inactive[] PROGMEM =  "\tEMS: Channel 2 inactive";
const char ems_channel_1_intensity[] PROGMEM = "\tEMS: Intensity Channel 1: ";
const char ems_channel_2_intensity[] PROGMEM = "\tEMS: Intensity Channel 2: ";

const char* const string_table_outputs[] PROGMEM = {ems_channel_1_active, ems_channel_1_inactive, ems_channel_2_active, ems_channel_2_inactive, ems_channel_1_intensity, ems_channel_2_intensity};

char buffer[32];

//process a command message (according to protocol, check github for that)
void processMessage(String message) {
  if (message.charAt(0) == 'W' && message.charAt(1) == 'V') {
    int lastIndexOfComma = message.lastIndexOf(',');
    hexCommandString = message.substring(lastIndexOfComma + 1,
    message.length() - 1);
    command = "";
    printer("\tEMS_CMD: HEX command length: ");
    printer(String(hexCommandString.length()));
    printer(hexCommandString);
    for (unsigned int i = 0; i < hexCommandString.length(); i = i + 2) {
      char nextChar = convertToHexCharsToOneByte(hexCommandString.charAt(i),hexCommandString.charAt(i + 1));
      command = command + nextChar;
    }
    printer("\tEMS_CMD: Converted HEX command: ");
    printer(command);
    emsSystem.doCommand(&command);
  } else if (message.equals(BTLE_DISCONNECT)) {
    printer("\tBT: Disconnected");
    emsSystem.shutDown();
  }
  else {
    printer("\tCommand NON HEX:");
    printer(message);
    doCommand(message[0]);
  }
}



// TESTING COMMANDS
//   For quick testing (e.g., opening the optocoupler ports, etc) you can use these single-char commands (one command = one char).
//   The cavailable commands are:
//     "1": toggles the channel 1 between open/closed state (when the channel is closed, the potenciometer position is reset to minimum, i.e., 255)
//     "2": toggles the channel 1 between open/closed state (when the channel is closed, the potenciometer position is reset to minimum, i.e., 255)
//     "q": increases EMS signal on channel 1 by decreasing the digital potenciometer wiper position (i.e., resistance lowers and more EMS is passing)
//           -> note that you have full EMS signal when the potentiometer wiper is at 0 (0 is the maximum)
//     "a": decreases EMS signal on channel 1 by increasing the digital potenciometer wiper position (i.e., resistance lowers and more EMS is passing)
//           -> note that you have no EMS signal when the potentiometer wiper is at 255 (255 is the maximum resistance of the potentiometer)
//     "w": increases EMS signal on channel 2 by decreasing the digital potenciometer wiper position (i.e., resistance lowers and more EMS is passing)
//           -> note that you have full EMS signal when the potentiometer wiper is at 0 (0 is the maximum)
//     "s": decreases EMS signal on channel 2 by increasing the digital potenciometer wiper position (i.e., resistance lowers and more EMS is passing)
//           -> note that you have no EMS signal when the potentiometer wiper is at 255 (255 is the maximum resistance of the potentiometer)
void doCommand(char c) {
      if (c == '1') {
      if (emsChannel1.isActivated()) {
         emsChannel1.deactivate();
      strcpy_P(buffer, (char*)pgm_read_word(&(string_table_outputs[1])));
         printer(buffer); //"\tEMS: Channel 1 inactive"
      } else {
         emsChannel1.activate();
      strcpy_P(buffer, (char*)pgm_read_word(&(string_table_outputs[0])));
         printer(buffer); //"\tEMS: Channel 1x active"
      }
   } else if (c == '2') {
      if (emsChannel2.isActivated()) {
         emsChannel2.deactivate();
      strcpy_P(buffer, (char*)pgm_read_word(&(string_table_outputs[3])));
         printer(buffer); //"\tEMS: Channel 2 inactive"
      } else {
         emsChannel2.activate();
      strcpy_P(buffer, (char*)pgm_read_word(&(string_table_outputs[2])));
         printer(buffer);  //"\tEMS: Channel 2 inactive"
      }
   } else if (c == 'a') {
      digitalPot.setPosition(1, digitalPot.getPosition(1) + 1);
    strcpy_P(buffer, (char*)pgm_read_word(&(string_table_outputs[4])));
      printer(
            buffer + String(digitalPot.getPosition(1))); //"\tEMS: Intensity Channel 1: "
   } else if (c == 'q') {
    strcpy_P(buffer, (char*)pgm_read_word(&(string_table_outputs[4])));
      digitalPot.setPosition(1, digitalPot.getPosition(1) - 1);
      printer(
            buffer + String(digitalPot.getPosition(1))); //"\tEMS: Intensity Channel 1: "
   } else if (c == 's') {
      //Note that this is channel 3 on Digipot but EMS channel 2
      digitalPot.setPosition(3, digitalPot.getPosition(3) + 1);
   strcpy_P(buffer, (char*)pgm_read_word(&(string_table_outputs[5])));
      printer(
            buffer + String(digitalPot.getPosition(3))); //"\tEMS: Intensity Channel 2: "
   } else if (c == 'w') {
      //Note that this is channel 3 on Digipot but EMS channel 2
      digitalPot.setPosition(3, digitalPot.getPosition(3) - 1);
   strcpy_P(buffer, (char*)pgm_read_word(&(string_table_outputs[5])));
      printer(
            buffer + String(digitalPot.getPosition(3))); //"\tEMS: Intensity Channel 2: "
   }
        else printer("\tERROR: SINGLE-CHAR Command Unknown");
}

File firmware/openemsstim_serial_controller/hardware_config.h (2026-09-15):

/**
 * hardware_config.h
 * ------------------
 * This file does NOT invent any pin numbers. The actual pin wiring for the
 * EMS channels comes from openemsstim_serial_controller.ino's own object
 * constructors:
 *
 *     EMSChannel emsChannel1(6, 7, A3, &digitalPot, 3);
 *     EMSChannel emsChannel2(5, 4, A2, &digitalPot, 1);
 *     AD5252     digitalPot(0);
 *
 * NOTE: this is the SWAPPED order relative to the original openEMSstim
 * example (which pairs (5,4,A2)=channel1 / (6,7,A3)=channel2). We confirmed
 * with LED/multimeter + on-arm testing that on our actual board, the output
 * physically labeled "channel 1" comes out of the (6,7,A3) wiring, not
 * (5,4,A2) -- so the two EMSChannel(...) lines were swapped to match.
 *
 * >>> If you rewire the board or swap to a different unit, re-verify this
 * >>> with LED/multimeter before trusting it again -- don't assume the
 * >>> mapping above still holds.
 *
 * Everything in *this* file is our own add-on configuration -- channel
 * enable flags, protocol timing, and the Bluetooth on/off switch -- none of
 * which is hardware pin data.
 */

#ifndef HARDWARE_CONFIG_H_
#define HARDWARE_CONFIG_H_

// --- Channel availability -------------------------------------------------
// Channel 2's hardware was repaired and re-tested -- both channels enabled.
// If channel 2 breaks again, flip this back to false; no other code changes
// are needed for the serial protocol to stop/start accepting channel-2
// commands.
#define CHANNEL_1_ENABLED true
#define CHANNEL_2_ENABLED true

// --- Bluetooth / RN4020 ----------------------------------------------------
// The prelim explicitly does not use BLE/RN4020. Set to 1 to restore the
// official firmware's Bluetooth init/read path unchanged if you revive it
// for the finals.
#define ENABLE_BLUETOOTH_MODULE 0

// --- Serial protocol -------------------------------------------------------
// Must match config.py's SerialConfig.baud_rate on the PC side.
#define SERIAL_BAUD_RATE 19200

// If no valid line arrives from the PC within this many ms while a channel
// is armed, the Arduino deactivates every channel on its own (independent of
// whatever the PC thinks is happening). This is the firmware-side half of
// the heartbeat safety requirement; serial_link.py / app.js send PING every
// ~400ms automatically, so 1500 is fine for real software.
//
// TEMPORARILY set to 10000 for manual Serial Monitor bench testing (a human
// typing commands by hand is much slower than 1500ms between lines). Set
// this back to 1500 before connecting the real PC software for actual runs
// -- a human typing is not an acceptable substitute for the real watchdog
// once anything is actually attached to a person.
#define HEARTBEAT_TIMEOUT_MS 1500

// Every SET command must carry a duration; this is the ceiling we enforce
// here even if a PC bug asks for longer. Mirrors the official firmware's own
// 5000ms cap inside EMSSystem::doActionCommand.
#define MAX_COMMAND_TTL_MS 5000

#endif /* HARDWARE_CONFIG_H_ */

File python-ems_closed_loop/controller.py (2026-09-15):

"""
controller.py
--------------
The closed-loop control law: takes (target %, current %) and produces the
next EMS control value (0-100, called `intensity_level` everywhere -- this is
NOT milliamps, see EMSChannel.setIntensity in the official openEMSstim
firmware).

Two interchangeable modes:
  - "proportional" (default): safety-limited step-wise P control. Every tick
    it can only move the intensity by at most `max_step_up`/`max_step_down`,
    so a bad reading or an aggressive command can never cause a big jump.
  - "pid": full PID with a clamped integral term (anti-windup) for when P
    alone settles too slowly. Still passes through the exact same step-size
    and final-value safety clamps.

This module never talks to hardware and never touches OpenCV/MediaPipe. It
only does arithmetic, so it is fully unit-testable (see tests/test_controller.py)
and is exactly what simulator.py exercises before any real hardware exists.
"""

from __future__ import annotations

import time
from dataclasses import dataclass
from enum import Enum
from typing import Optional

from config import ControlConfig
from safety_manager import SafetyManager


class ControlState(Enum):
    IDLE = "대기"
    WAITING_FOR_HAND = "손 인식 중"
    INCREASING = "자극 증가"
    DECREASING = "자극 감소"
    HOLDING = "목표 유지 중"
    SUCCESS = "성공"
    SAFETY_STOP = "안전 정지"


@dataclass
class ControlDecision:
    intensity: int
    state: ControlState
    error: Optional[float]
    message: str = ""


class ClosedLoopController:
    def __init__(self, config: ControlConfig, safety: SafetyManager):
        self.config = config
        self.safety = safety

        self.target_percent: Optional[float] = None
        self._intensity: int = 0

        self._success_since: Optional[float] = None
        self._last_step_time: float = 0.0

        # PID-only state
        self._integral: float = 0.0
        self._last_error: float = 0.0
        self._last_pid_time: Optional[float] = None

    # ------------------------------------------------------------------ #

    @property
    def intensity(self) -> int:
        return self._intensity

    def set_target(self, target_percent: float, initial_intensity: Optional[int] = None) -> None:
        """Start pursuing a new target. `initial_intensity`, if given (e.g.
        from adaptive_model's suggestion), seeds the starting output instead
        of 0 -- it is still clamped by SafetyManager either way, and the
        camera feedback loop corrects it from there regardless of how good
        the initial guess was."""
        self.target_percent = max(0.0, min(100.0, target_percent))
        self._success_since = None
        self._last_step_time = 0.0
        self._integral = 0.0
        self._last_pid_time = None
        if initial_intensity is not None:
            self._intensity = self.safety.clamp_working_intensity(initial_intensity)

    def force_zero(self, reason: str = "") -> ControlDecision:
        """Immediate, ungated drop to zero. Used by the safety layer -- this
        deliberately bypasses max_step_down because getting the current OFF
        is always safe, unlike ramping it up."""
        self._intensity = 0
        self.target_percent = None
        self._success_since = None
        return ControlDecision(0, ControlState.SAFETY_STOP, None, reason)

    def reset(self) -> None:
        self.target_percent = None
        self._intensity = 0
        self._success_since = None
        self._integral = 0.0
        self._last_pid_time = None

    # ------------------------------------------------------------------ #

    def update(self, current_percent: Optional[float], now: Optional[float] = None) -> ControlDecision:
        now = now if now is not None else time.monotonic()

        if self.target_percent is None:
            return ControlDecision(self._intensity, ControlState.IDLE, None, "목표 없음")

        if current_percent is None:
            self._success_since = None
            return ControlDecision(
                self._intensity, ControlState.WAITING_FOR_HAND, None, "손을 인식하지 못했습니다"
            )

        error = self.target_percent - current_percent

        if abs(error) <= self.config.tolerance_percent:
            if self._success_since is None:
                self._success_since = now
            held_for = now - self._success_since
            if held_for >= self.config.success_hold_seconds:
                self._intensity = 0
                # Clear the target so SUCCESS is a terminal state, not a
                # transient one. Without this, next tick would still see a
                # target percent while intensity=0 (stimulation just cut
                # off) -- as the hand relaxes back open, error would grow
                # again and the controller would swing right back into
                # INCREASING, defeating "성공 즉시 EMS를 정지한다" by turning
                # SUCCESS into a permanent increase/hold/success oscillation
                # instead of an actual stop. A fresh command is required to
                # pursue a new target after this.
                self.target_percent = None
                return ControlDecision(0, ControlState.SUCCESS, error, f"목표 달성 (오차 {error:+.1f}%)")
            return ControlDecision(
                self._intensity, ControlState.HOLDING, error, f"목표 유지 중 ({held_for:.1f}s)"
            )
        else:
            self._success_since = None

        # Settling time: only actually change the output every control_period_s,
        # even if update() is called once per camera frame.
        if now - self._last_step_time < self.config.control_period_s:
            state = ControlState.INCREASING if error > 0 else ControlState.DECREASING
            return ControlDecision(self._intensity, state, error, "안정화 대기 중")

        self._last_step_time = now

        if self.config.mode == "pid":
            raw_step = self._pid_step(error, now)
        else:
            raw_step = self.config.kp * error

        step = max(-self.config.max_step_down, min(self.config.max_step_up, raw_step))
        # Generic 0-100 sanity bound only -- the human-safety hardware ceiling
        # (safety_max_intensity) is applied once, at the point a value is
        # actually about to be sent to real EMS hardware (main.py._drive_hardware),
        # not here. See SafetyManager.clamp_working_intensity's docstring.
        new_intensity = self.safety.clamp_working_intensity(self._intensity + step)
        self._intensity = new_intensity

        if step > 0.01:
            state = ControlState.INCREASING
        elif step < -0.01:
            state = ControlState.DECREASING
        else:
            state = ControlState.HOLDING

        return ControlDecision(new_intensity, state, error, f"step={step:+.1f} -> {new_intensity}")

    def _pid_step(self, error: float, now: float) -> float:
        dt = (now - self._last_pid_time) if self._last_pid_time is not None else self.config.control_period_s
        dt = max(dt, 1e-3)
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

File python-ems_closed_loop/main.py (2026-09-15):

"""
main.py
--------
Entry point. Wires config -> safety -> vision/simulator -> serial/simulator
-> controller -> adaptive model -> data logger -> command interpreter, runs
the whole pipeline in a background worker thread, and hands a thread-safe
snapshot of the current state to the Tkinter GUI (gui.py), which owns the
main thread as required by Tkinter.

Run modes (see README.md "실행 방법" for the full walkthrough):

    python main.py
        Full simulation. No camera, no Arduino required. This is the
        default and the ONLY mode that runs without any flags -- by design.

    python main.py --live-camera
        Real camera + MediaPipe, simulated Arduino/EMS (hand bend is real,
        stimulation is not). Useful for tuning calibration/control without
        touching hardware.

    python main.py --live-serial
        Real Arduino over serial, simulated hand (no camera). Useful for the
        "Arduino 단독 통신 검증" step in the README before any human/LED test.

    python main.py --live
        Both real. Requires config.json's safety.safety_max_intensity > 0
        (set deliberately by a person) or every real SET command is refused
        by safety_manager regardless of this flag.
"""

from __future__ import annotations

import argparse
import threading
import time
from dataclasses import dataclass, field
from pathlib import Path
from typing import Optional

from adaptive_model import AdaptivePersonalizationModel
from command_interpreter import CommandInterpreter, CommandResult
from config import AppConfig, load_config, resolve_path
from controller import ClosedLoopController, ControlState
from data_logger import DataLogger, LogRow
from safety_manager import SafetyManager
from serial_link import SerialLink
from simulator import HandDynamicsSimulator, SimulatedArduino
from vision_tracker import VisionTracker

SIM_LOOP_HZ = 30.0


@dataclass
class Snapshot:
    """Read-only-by-convention state the GUI polls. Always copy, never
    mutate a Snapshot instance you were handed."""
    live_camera: bool = False
    live_serial: bool = False

    vision_ready: bool = False
    vision_error: str = ""
    hand_detected: bool = False
    hand_lost: bool = True
    is_calibrated: bool = False
    calibration_active: bool = False
    calibration_progress: tuple[int, int] = (0, 0)

    serial_connected: bool = False
    serial_handshake: bool = False
    serial_error: str = ""

    target_percent: Optional[float] = None
    current_percent: Optional[float] = None
    ems_intensity: int = 0
    error_percent: Optional[float] = None
    control_state: str = ControlState.IDLE.value
    success: bool = False

    last_command_text: str = ""
    last_message: str = ""

    elapsed_s: float = 0.0
    cooldown_remaining_s: float = 0.0

    frame_bgr: object = None  # numpy array or None; typed loosely to avoid importing cv2/np here
    history: list = field(default_factory=list)  # list[(t, target, current, intensity)] for the GUI graphs

    quit_requested: bool = False


class ControlLoopWorker:
    def __init__(self, config: AppConfig, live_camera: bool, live_serial: bool):
        self.config = config
        self.live_camera = live_camera
        self.live_serial = live_serial

        self.safety = SafetyManager(config.safety)
        self.controller = ClosedLoopController(config.control, self.safety)
        self.interpreter = CommandInterpreter(config.presets)
        self.adaptive_model = AdaptivePersonalizationModel(config.adaptive_model, self.safety)
        self.data_logger = DataLogger(resolve_path(config.logging.log_dir))

        self._hand_sim: Optional[HandDynamicsSimulator] = None
        self.vision: Optional[VisionTracker] = None
        self.stim: Optional[SimulatedArduino | SerialLink] = None

        self._lock = threading.Lock()
        self._snapshot = Snapshot(live_camera=live_camera, live_serial=live_serial)
        self._history: list[tuple[float, Optional[float], Optional[float], int]] = []

        self._pending_command: Optional[str] = None
        self._pending_percent: Optional[float] = None  # from quick-preset buttons
        self._pending_calibration: Optional[str] = None
        self._quit_requested = False
        self._stop_event = threading.Event()
        self._armed_ch1 = False

        self.safety.on_emergency_stop(self._on_emergency_stop)

        model_path = resolve_path(config.adaptive_model.model_path)
        self.adaptive_model.load(model_path)

    # ------------------------------------------------------------------ #
    # Setup
    # ------------------------------------------------------------------ #

    def initialize(self) -> None:
        model_asset = resolve_path(config_model_path(self.config))

        if self.live_camera:
            self.vision = VisionTracker(self.config.camera, self.config.hand_tracking, model_asset)
            try:
                self.vision.start()
            except RuntimeError as exc:
                self._set(vision_error=str(exc), vision_ready=False)
                self.vision = None
        else:
            self._hand_sim = HandDynamicsSimulator()
            self._set(vision_ready=True)
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

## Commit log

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2026-09-15 테스트 모드: 안전 최대값 클램프·비상정지 상태 체크 제거 (전기 주기+세기 설정만 남김)
2026-09-15 개인화 모드를 행동 보조 모드 안으로 통합 (모드 4개로 축소, 상호 정지 로직 추가)
2026-09-15 팔 인식 모드에 손 굽힘 참고 표시 추가 (팔꿈치+손 동시 측정, 페이지 정리)
2026-09-15 버그 수정: 팔 TARGET/ACTUAL 역할을 매 프레임 x좌표로 재판정하던 걸 고정 판정+체크박스로 변경
2026-09-15 버그 수정: 테스트 모드 방향키 반복입력이 시리얼 큐에 쌓여 정지가 늦어지던 문제 (재전송 간격 제한)
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2026-09-15 버그 수정: 팔 인식 모드 좌우 반전(손처럼 미러링 화면에서 기본적으로 뒤집혀 인식됨)
2026-09-15 비상정지 전수 점검: safetyTripped를 트립 순간만이 아니라 매 tick 확인하도록 수정 (거울모드/팔인식모드/개인화캘리브레이션) + 팔 인식 모드 과도굽힘 시 세기 감소 기능 추가
2026-09-15 속도 조정: 오르내리는 속도를 동일하게 통일하고 30%p 감속 + 팔인식모드 프레임마다 갱신되던 속도 제한 버그 수정 + localStorage에 안 쓰이는 control 값 고정되던 문제 수정
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2026-09-15 행동 보조 모드를 목표 %(카메라 폐루프) 자동 세팅 방식으로 전환
    - 수저 들기 보조/이두운동: 채널1/2 전류 직접입력 -> 손/팔꿈치 목표 % 입력으로 변경
    - 팔 인식 모드의 stepFlexOnlyAxis/driveArmHardwareIfNeeded 폐루프 엔진 재사용
    - 이두운동: 굽힘/이완 반복이 고정 시간표 대신 실제 목표 도달(LOCKED) 기준으로 자동 진행
    - 시작 전 손+팔 캘리브레이션 확인, 팔 인식 모델 자동 로딩
    - 회원 개인화 저장값을 채널 전류 -> 목표 %로 변경
    - 행동 보조 모드에서도 필요할 때 Pose 모델 실행되도록 렌더루프 조건 확장
    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
2026-09-15 버그 수정: 팔 인식 모드 하드웨어 재전송 주기가 TTL보다 길어서 자극이 끊겼다 이어졌다 하던 문제 (600ms로 단축) + 속도 2배 상향
2026-09-15 팔 인식 모드 속도/유지 버그 수정, 수저 들기 순차 진행, 전 모드 팔 인식 확대
    - 세기 증가/감소가 큰 폭으로 "점프"해 보이던 문제를 고쳤다: maxStepUp/
    maxStepDown을 5.1 -> 1로 낮춰 진짜 1씩 점진적으로 오르게 하고,
    controlPeriodMs를 6000 -> 2250(실제 주기 900ms)으로 조정해 목표 도달
    시간이 대략 예전의 2배가 되도록 맞췄다.
    - 목표에 도달해 LOCKED로 계속 유지하는 상태가 config.safety.
    maxContinuousStimSeconds(연속 자극 제한, 기본 10초)에 그대로 걸려 "몇 초
    뒤 혼자 꺼짐"으로 보이던 문제 수정 -- 기본값을 60초로 올리고, 이미
    localStorag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
2026-09-15 행동 보조 모드에서 팔 인식이 안 되던 문제 수정
    renderLoop의 Pose 실행 조건이 행동 보조 모드에 한해서만
    "runningActionKey !== null"(실행 버튼을 눌러야만) 켜지게 되어 있어서,
    화면에 들어가기만 하고 아직 실행 전이면 팔 인식이 전혀 안 됐다
    (테스트 모드는 appMode 조건 하나뿐이라 바로 됐음). 거울 모드를 제외한
    모든 모드에서 화면 진입 즉시 Pose가 켜지도록 통일 -- 카메라 시작 시
    모델을 미리 불러오는 조건, setAppMode의 사전 로딩 조건도 함께 맞춤.
2026-09-15 수저 들기 보조: 팔꿈치 목표 도달해도 전류가 안 멈추던 버그 수정
    spoonLiftTick의 마지막 단계("elbow" LOCKED -> "done")에서 phase만
    바꾸고 더 이상 stepFlexOnlyAxis를 호출하지 않게 해뒀는데, 그러면
    actionElbowCtrl.intensity가 마지막 계산값에 "그대로 얼어붙은 채" 계속
    하드웨어로 재전송됐다 -- 목표만큼 구부러졌는데도 전류가 안 멈추던
    원인. 팔꿈치까지 목표에 도달(LOCKED)하면 실제로 stopActionMode()를
    불러 두 채널 다 0으로 정지하고 행동을 완료 처리하도록 수정 (이두운동의
    마지막 반복 완료 처리와 동일한 방식으로 통일).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
2026-09-15 개인화 측정(수동 램프업)을 안전 최대값 설정 도구로 재연결
    수저/이두운동이 폐루프(목표%)로 바뀐 뒤로 이 측정값이 화면에만 표시되고
    어디에도 안 쓰이던 문제를 "재사용"으로 해결. A키로 멈춰서 잰 세기를
    "🛡 이 값을 안전 최대값으로 설정" 버튼으로 config.safety.maxIntensity(③
    카드)에 바로 채워 넣을 수 있게 함 -- 폐루프는 카메라가 목표%에 도달할
    때까지 세기를 계속 올리기만 할 뿐 그 사람이 아파하는지는 모르므로, 미리
    사람마다 견딜 수 있는 한계치를 재서 상한으로 걸어두는 용도.
    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
2026-09-15 테스트 모드: 채널1/채널2 세기를 따로 설정 가능하게 변경
    기존엔 testIntensityInput 하나를 두 채널이 같이 썼는데, ←(채널1)/→(채널2)
    세기를 각각 입력하는 별도 칸(testIntensityCh1Input/testIntensityCh2Input)으로
    나눴다.
2026-09-15 테스트 모드: 방향키를 누르고 있는 동안 전류가 주기적으로 끊기던 버그 수정
    기존엔 브라우저의 keydown "자동 반복" 이벤트가 올 때마다 재전송하는
    방식이었는데, 이 반복 간격이 OS/브라우저 설정에 따라 들쭉날쭉해서 TTL
    (600ms)보다 늦게 오는 경우 그 사이 잠깐씩 전류가 끊겼다. keydown은 눌린
    첫 순간에만 반응하고, 그때부터 별도 setInterval(TEST_RESEND_MS=200ms)이
    키를 뗄 때까지 계속 재전송하도록 바꿔서 OS/브라우저의 키 반복 타이밍과
    완전히 무관하게 끊김 없이 나가도록 수정.
2026-09-15 테스트 모드: 재전송이 시리얼 큐에 밀려 주기적으로 끊기던 진짜 원인 수정
    키 반복 타이밍과 무관하게 만든 지난 수정 뒤에도 여전히 "왔다 안 왔다"
    하던 원인을 다시 봄 -- TEST_RESEND_MS(200ms)마다 무조건 새로 SET을
    보내고 있었는데, SET 하나가 실제로 응답(OK/ERROR)받기까지 그보다 오래
    걸리면(직렬 통신 왕복 지연 등) WebSerialLink의 명령 큐(_chain)에 다음
    SET이 계속 쌓인다. 큐가 밀리면 실제 도착 시점이 점점 늦어져서 앞서 보낸
    SET의 TTL이 먼저 만료돼 채널이 꺼졌다가, 밀려있던 다음 SET이 뒤늦게
    도착해 다시 켜지는 식으로 반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
2026-09-15 행동 보조 모드 개인화 측정 대대적 개편: 수동 램프업 -> 목표 도달 세기 자동 탐색
    회원번호 입력 섹션 밑을 다음 순서로 재구성:
    1) 🥄 수저 보조 / 💪 이두운동 선택 버튼 2개 (지금 측정 결과를 어느 행동에
    저장할지 고르는 용도)
    2) 손 목표 %, 팔꿈치 목표 % 입력칸
    3) ▶ 개인화 측정 시작 버튼
    시작하면 spoonLiftTick과 같은 원리로 손 -> 팔꿈치 순서로 전류를 자동으로
    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
2026-09-15 왼팔/오른팔 구부림 % 비대칭 버그 수정 -- 양팔 각자 보정값으로 분리
    같은 각도만큼 구부려도 왼팔 %가 오른팔보다 낮게 나오던 원인: 팔
    초기값 측정(펴짐/구부림)이 오른팔(actual)만 재고, 그 하나의 각도
    범위를 왼팔(source)에도 그대로 재사용하고 있었다(카메라 각도/팔
    길이 차이 등으로 두 팔이 실제로는 다른 각도 범위를 가짐). 이 값은
    단순 표시용이 아니라 팔 인식 모드에서 왼팔 %가 오른팔의 실제 목표
    (TARGET)로 그대로 쓰이므로, 표시 오차가 아니라 목표 자체가 틀어지는
    문제였다.
    팔 초기값 측정 시 양팔을 동시에 재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
2026-09-16 테스트 모드에 남아있던 "안전 정지 상태" 표시 제거
    원인: 모드를 바꿀 때마다 호출되는 forceZeroController()가 정리 목적으로
    공용 상태 표시(controlState)를 항상 "SAFETY_STOP"으로 남겨두는데,
    거울/팔인식/행동보조 모드는 다음 tick에서 자기 상태로 바로 덮어써서
    문제가 안 됐지만, 테스트 모드는 controlState를 아예 안 건드리는 모드라
    이 값이 그대로 남아 실제로는 안전장치가 없는 모드인데도 "안전 정지
    상태"가 계속 표시되고 있었다.
    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
2026-09-16 발표용: 팔 인식 모드 주요 숫자(TARGET/ACTUAL/오차/EMS 제어값) 크게 표시
    .compare-value 24px -> 38px, .stim-value 32px -> 48px, .compare-label
    11.5px -> 14px, .state-line 13px -> 16px로 확대(공용 CSS라 팔 인식
    모드 외 다른 모드에도 동일하게 적용됨). 팔 인식 모드의 손(채널1) 섹션에
    따로 걸려있던 더 작은 인라인 크기(20px/22px)도 제거해서 같이 커지게
    했고, 손 상태 텍스트도 20px로 키움.
    곁다리로, 안내 문구에 남아있던 "연속 자극 시간 제한(기본 10초)"도
    지난번에 기본값을 60초로 올린 뒤로 안 고쳐져 있던 걸 발견해 같이 수정.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
2026-09-16 발표용: "손가락별 목표 vs 실제" 표 화면에서 숨김
    카드 자체를 지우면 관련 JS(updateFingerTable 등)가 참조하는 DOM이
    없어져 오류가 날 수 있어, 안전하게 display:none으로 화면에서만
    숨김(내부 계산/저장은 그대로 계속됨 -- 필요하면 언제든 다시 보이게
    되돌릴 수 있음).
2026-09-16 회원 개인화 섹션에 "저장" 버튼 추가 (불러오기/회원 등록 옆)
    registerMember()가 원래도 새 회원 등록과 기존 회원 값 갱신을 둘 다
    처리하는 upsert라서, 새 로직 없이 같은 함수를 호출하는 버튼만 하나
    더 추가했다 -- 이름을 몰라 헷갈리지 않게 registerMember(btn)이 실제로
    눌린 버튼을 받아 그 버튼에 "저장됨!" 플래시가 뜨도록 함께 수정.
2026-09-16 발표용: 행동 보조 모드(수저/이두운동)도 팔인식 모드처럼 큰 숫자로 표시
    지금까지 수저 들기 보조/이두운동은 손·팔꿈치 상태를 "INCREASING (12)"
    같은 작은 초록색 한 줄(state-line)로만 보여줘서, 손 쪽은 그나마 ⑤
    카드의 큰 ACTUAL 숫자(항상 손 평균이 표시됨)로 커버됐지만 팔꿈치 쪽은
    작은 글씨로만 보였다. 팔 인식 모드의 손(채널1) 섹션과 똑같은 스타일
    (TARGET/ACTUAL/오차 큰 칸 + EMS 세기 칸)을 손·팔꿈치 양쪽에 다 추가.
    중복 코드를 없애려고 팔 인식 모드에서 손코딩돼 있던 TARGET/ACTUAL/오차
    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
2026-09-16 수저 들기 보조/이두운동 실행 버튼을 나란히 배치하고, 숫자 표시를 4개->2개로 통합
    두 행동이 동시에 돌 수 없는데도(runningActionKey 하나뿐) 각자 따로
    손/팔꿈치 TARGET·ACTUAL·오차·세기 칸을 갖고 있어서 화면에 항상 4벌이
    같이 보였다 -- 실행 안 하는 쪽은 계속 "-"만 떠 있어서 어느 게 실제
    값인지 헷갈리기 쉬웠다("수치가 안 나온다"는 것도 이 혼란 때문이었을
    가능성이 큼). "손" 1벌, "팔꿈치" 1벌만 공용으로 두고, 지금 실행 중인
    쪽(spoonLiftTick 또는 bicepClosedLoopTick)이 그때그때 채워쓰도록
    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
2026-09-16 팔 초기값 측정을 ② 카드 바로 다음으로 옮김 (③ 안전 설정보다 앞)
    기존엔 팔 인식 모드 카드 안(③ 안전 설정보다도 뒤, 손 굽힘 표시 섹션
    다음)에 있어서, 손가락 초기값 측정 직후 이어서 팔 초기값까지 측정하려면
    안전 설정 카드를 거쳐 스크롤해야 했다. 팔 초기값 측정을 독립된 카드로
    빼서 ② 초기값 측정(손가락) 바로 다음, ③ 안전 설정보다 앞에 배치.
    행동 보조 모드도 이 값이 있어야 실행되므로(actionCalibrationReady),
    이 카드는 팔 인식 모드뿐 아니라 행동 보조 모드에서도 보이게 함 --
    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
2026-09-16 행동 보조 모드에서 ⑤ 카드의 TARGET/ACTUAL/제어 패널 숨김
    이 패널(TARGET/ACTUAL/오차 + 제어 시작/해제 버튼 + 판단 상태)은 거울
    모드/팔 인식 모드가 실제로 쓰는 공용 controlEnabled 플로우를 보여주는
    건데, 행동 보조 모드는 자기만의 실행 버튼/폐루프를 따로 쓰고 이
    플로우를 전혀 안 써서 행동 보조 모드에서는 항상 대기중/0으로 고정돼
    있었다. 방금 추가한 손/팔꿈치 큰 칸과 헷갈릴 수 있어 행동 보조 모드일
    땐 이 패널만 숨기고(기록 로그는 모든 모드 공용이라 계속 보여줌).
2026-09-16 수저 들기 보조: 손/팔꿈치 동시 진행으로 되돌리고, 전체 속도 3배 증가
    손이 먼저 목표에 도달해야 팔꿈치로 넘어가던 순차 진행을, 실제 수저
    드는 동작은 손을 쥐는 것과 팔꿈치를 드는 게 동시에 일어나야 자연스럽다는
    피드백에 따라 다시 동시 진행으로 되돌림 -- 손/팔꿈치 둘 다 매 tick
    목표를 향해 같이 움직이고, 각자 도달하면 그 축만 유지하다가 둘 다
    도달하면 완료 처리(정지)한다. "도달해도 전류 안 멈추던" 이전 버그와
    같은 종류의 문제가 재발하지 않게, 완료 조건도 그때와 동일한 방식으로
    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
2026-09-16 CSV 다운로드를 시행(trial) 기준 요약으로 재설계
    예전엔 카메라 프레임마다 한 줄씩(수천 줄) 그대로 CSV로 내보내서 사람이
    "몇 번 시도해서 몇 번 성공했는지" 알아보기 어려웠다. 이제 목표에
    도달(LOCKED)할 때마다 1회 성공으로 기록하고, 12초 안에 도달 못하면
    그 시도를 실패로 기록한 뒤 바로 다음 시도 관찰을 시작한다
    (updateTrialTracking, controlEnabled로 실제 목표를 쫓는 동안만 관찰 --
    거울 모드/팔 인식 모드에서 동작, 둘 다 공용 controlState를 씀).
    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
2026-09-16 "개인화 캘리브레이션 (선택)" 카드 화면에서 숨김
    관련 JS가 참조하는 DOM을 남겨두기 위해 완전히 지우지 않고
    display:none으로 숨김 (손가락별 목표 vs 실제 표를 숨긴 것과 동일한 방식).
2026-09-16 행동 보조 모드: 회원번호 시스템 제거, 설정을 컴퓨터 공용으로 저장
    회원번호별로 목표%를 따로 저장하던 방식(loadMembers/saveMembers,
    emsWebMembers)을 없애고, 이 컴퓨터에서 마지막으로 저장한 값 하나만
    기억하는 방식(loadActionSettings/saveActionSettings, emsWebActionSettings)
    으로 바꿨다. 수저 들기 보조/이두운동 각 섹션에 자기 목표%(/반복 횟수)만
    저장하는 "저장" 버튼을 추가(saveActionInputs) -- 페이지를 새로 열면
    applyStoredActionSettings()가 자동으로 다시 채운다.
    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
2026-09-16 거울 모드: 컵 잡기/따르기/흔들기 등 미리 정의된 행동 버튼 제거 + 실시간 왼손 연동 타겟 표시 버그 수정
    - 컵 잡기/따르기 동작/흔들기 동작/팔 굽히기/물건 놓기 버튼(ACTIONS 배열,
    buildActionButtons/selectAction)을 제거. 전부 실측 데이터가 아닌
    placeholder 목표값이었고, 거울 모드는 실시간 왼손 연동 하나로 충분하다고
    판단. selectedActionText/actionDescriptionText는 실시간 왼손 연동
    전용 상태 표시로 재활용(대기 중 / 연동 중).
    - ⚠ 버그 수정: "실시간 왼손 연동 시작"을 눌러도 targetPercent 갱신
    (updateLiveMirrorTarget)이 controlEnabled(=▶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
2026-09-16 행동 보조 모드: 이두운동/수저 들기 보조 섹션·버튼 순서 교체
    id는 그대로 두고 화면에 나타나는 순서만 바꿔서(이두운동 -> 수저 들기
    보조, 실행 버튼도 이두운동 -> 수저 들기 보조 순), 기능은 전혀 손대지
    않음.
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2026-09-16 버그 수정: 페이지 로딩이 도중에 멈춰서 모드 버튼이 전혀 안 눌리던 문제
    원인: 마이크 자동 시작 코드(if (SpeechRecognitionCtor) toggleVoiceCommand();)
    가 파일 앞쪽(초기화 구간)에서 실행되는데, toggleVoiceCommand()가 참조하는
    voiceEnabled/voiceAwakeUntil/voicePendingBicepReps는 파일 훨씬 뒤쪽(음성
    비서 섹션)에 let으로 선언돼 있었다. 이 자동 시작 호출 시점엔 아직 그
    선언부에 도달하지 못했으므로 TDZ(Temporal Dead Zone)에 걸려 "Cannot
    access before initialization" 오류가 그 자리에서 던져졌고, 이 오류가
    잡히지 않은 채로 스크립트 전체 실행이 그 줄에서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
2026-09-16 음성 비서: AI 호출 실패 시 화면 글자뿐 아니라 소리로도 알려줌
    Gemini가 503(과부하)/네트워크 오류 등으로 응답 실패하면 이전엔 로그에만
    남고 사용자에게는 아무 반응이 없어서 왜 조용한지 알기 어려웠다.
    classifyVoiceIntentWithAI가 null(호출 실패)을 반환하면 speak()로도
    안내하도록 수정 (AI가 정상적으로 "관련 없음"이라고 판단한 경우와는
    구분해서, 실패했을 때만 이 안내가 나감).
2026-09-16 음성 비서: 한 번 명령 수행 후 "탱글아"를 다시 불러도 반응 없던 문제 수정
    브라우저 음성 인식 세션이 (특히 speak()로 응답한 뒤) 조용히 끊기는
    경우가 있는데, 그 직후 onend에서 바로 부르는 재시작(start())이 타이밍
    문제로 실패하면 그냥 조용히 포기하고 있었다 -- 그러면 voiceEnabled는
    여전히 true인데 실제 인식 세션은 죽어있는 상태가 돼서, 마이크를 껐다
    켜야만(다시 start() 호출) 원래대로 돌아왔다.
    voiceSessionActive(세션이 실제로 살아있는지)를 onstart/onend로 추적하고,
    0.5초마다 도는 watchdog(watchVoiceSession)이 "켜져 있어야 하는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
2026-09-16 이두운동: 굽힘 유지 단계 완전히 제거 -- 도달하면 바로 이완으로
    수축(굽힘) 완료 즉시(유지 없이) 이완 목표로 넘어가도록 변경. 관련
    BICEP_CURL_HOLD_MS 상수/holdStartedAt 상태/"hold" 단계를 전부 정리하고
    안내 문구도 맞춰 수정.
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2026-09-16 이두운동: 이완도 목표 이하 되면 LOCKED 기다리지 않고 바로 다음 단계로
    굽힘->이완 전환과 같은 방식으로, 이완 단계도 실제 %가 목표치에 도달하거나
    그 이하가 되는 즉시(LOCKED 대기 없이) 다음 반복(굽힘) 또는 완료 처리로
    넘어가도록 수정.
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2026-09-16 음성 비서: "N회" 발음이 어색하던 문제 수정 -- 숫자를 한글로 풀어서 읽게 함
    "이두운동 3회를 시작합니다"처럼 숫자+회를 그대로 speak()에 넘기면
    브라우저 한국어 TTS가 숫자와 단위 사이를 어색하게 끊어 읽는 경우가
    있었다. sinoKoreanNumber()로 숫자를 한글 한자어 수사로 변환해서
    ("이두운동 삼회를 시작합니다") 훨씬 자연스럽게 읽히도록 수정 -- 시작
    안내와 매 회차 카운트 음성 둘 다 적용.
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2026-09-17 손 좌우 뒤집기 체크박스와 팔 좌우 뒤집기 체크박스를 하나로 동기화
    카메라가 좌우로 뒤집혀 보이는 원인은 손/팔이 따로가 아니라 카메라 자체
    하나라서, 둘 중 아무 체크박스나 누르면 나머지 하나도 같은 상태로 같이
    바뀌게(체크박스 표시 + 실제 값 invertHandedness/invertArmSides 둘 다)
    동기화. 매번 두 군데 다 따로 체크할 필요 없어짐. 안내 문구도 서로
    연결되어 있음을 명시하도록 수정.
2026-09-17 버그 수정 2건: 목표 0에서도 전류 안 꺼지던 문제 / 테스트 모드 정지 지연 문제
    1) stepFlexOnlyAxis(팔 인식/행동 보조 공용)와 updateController(거울 모드)
    둘 다, 목표(targetPercent)가 거의 0인데 실제 굽힘도 마침 그 근처라서
    허용오차 안에 들어오면 "목표 도달 -- 유지" 분기를 타면서 그 순간까지
    남아있던 세기를 그대로 "유지"해버렸다. 목표가 낮아져서 0이 된 상황도
    이 분기로 들어가는데, 그러면 유지할 자세가 없는데도 전류가 안 꺼지는
    문제였다. 목표 자체가 허용오차 이하로 낮으면 세기를 0으로 내리도록 수정.
    2) 테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
2026-09-17 fix: 팔 인식/행동 보조 모드에서 목표가 낮아져도 전기가 안 줄어들던 문제 수정
    stepFlexOnlyAxis가 세기를 내릴 때도 올릴 때와 똑같이 300ms 주기에 1씩만
    내려가서, 실시간으로 계속 바뀌는 목표(왼손/반대팔 연동)가 훅 낮아져도
    액추얼이 한동안 목표보다 훨씬 높은 채로 남아 전기가 계속/더 세지는 것처럼
    보였다. 세기를 낮추는 건 안전 문제가 없으므로, 내려갈 때는 주기 제한 없이
    매 프레임 훨씬 빠르게(reduceKp/reduceMaxStep) 따라가도록 분리했다. 거울모드
    updateController()의 kpDown/maxStepDown(신전 채널 게인)은 건드리지 않았다.
    Co-A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
2026-09-17 fix: 행동 보조 모드에서 팔 인식 모델 첫 추론 워밍업 비용을 로딩 단계로 이동
    pose_landmarker_full.task(+720p)로 정확도를 올린 뒤로 첫 detectForVideo()
    호출에서 WASM 추론 커널이 그제서야 준비(JIT)돼 몇 초씩 걸렸는데, 이 비용이
    이두운동을 막 시작한 시점의 실제 프레임에 그대로 나가서 "초반엔 팔 엑추얼
    값이 측정 안 됨"으로 보였다. ensurePoseLandmarker()가 모델을 만든 직후
    빈 캔버스로 한 번 미리 detectForVideo를 호출해 그 워밍업 비용을 로딩
    토스트가 떠 있는 준비 단계에서 대신 치르게 했다.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
2026-09-18 docs: 최종 시연 문서/케이스 설계/초기 프로토타입 정리 (포트폴리오 이관용)
    - 기존 PDF 보고서 3개를 docs/로 이동, 전시판넬 PDF·설계정리 docx·재활보조
    시스템 보고서·시연 시 패치 위치 사진을 docs/에 추가
    - 발표 구술 초안을 정리해 docs/시연_대본_및_QA.md 작성 (신경가소성 정의 채워
    넣기, 근거 부족한 ±5% 수치는 일반화, 부정확하다고 지적된 표현은 대체 문구로
    교체, 확인이 필요한 메모는 별도 섹션으로 남김)
    - 보드 케이스 3D 프린팅 설계(STL)와 조립 영상을 hardware/case/에 추가
    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
    [emsboardcase (1).stl, emsboardcase (2).stl, 뚜껑.stl]
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
